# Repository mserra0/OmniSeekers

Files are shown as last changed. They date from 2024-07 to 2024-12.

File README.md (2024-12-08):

<div align="center">
 <a href="https://github.com/mserra0/OmniSeekers">
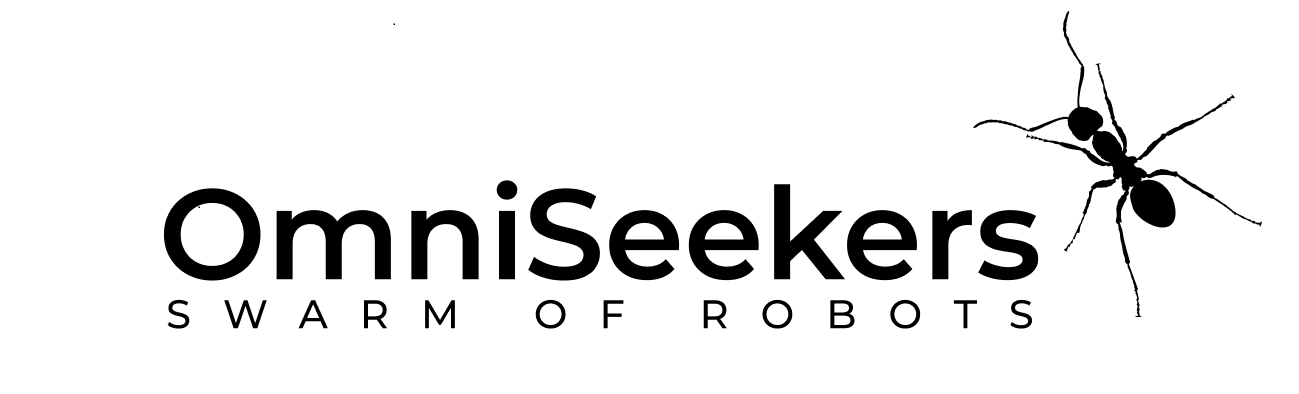
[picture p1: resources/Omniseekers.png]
    
 </a>
 <br/>
 <p align="center">
    Robotic project aimed at revolutionizing tasks such as Search and Rescue, with complete control of all robots in the swarm, also providing a promising development platform.
    <br />
 </p>
  <p align="center">
    <a href="https://www.youtube.com/watch?v=t2NAsWQEcVY&pp=ygULb21uaXNlZWtlcnM%3D">OmniSeekers Video Demo</a>
    <br />
 </p>
</div>

## Table of Contents
- [Description](#description)
  - [Structure](#structure)
  - [Dependencies](#dependencies)
- [Setup & Install](#setup--install)
- [Components](#components)
- [Details](#details)
  - [Software](#software)
  - [Hardware](#hardware)
- [Tools & Libraries](#tools--libraries)
  - [Tools](#software)
  - [Libraries](#hardware)
- [Technical Concepts](#technical-concepts)
  - [Bug Algorithm](#software)
  - [Odometry and Movement for 3-Wheeled Robots](#odometry-and-movement-for-3-wheeled-robots)
  - [Intra Robots Connection](#intra-robots-connection)
- [Demonstration](#demonstration)
- [To Do](#to-do)
- [References](#references)
- [Contributors](#contributors)
- [License](#license)

## Description
This project not only implements a swarm of omnidirectional robots but also serves as a multipurpose development platform. Designed to allow users to develop their own ideas affordably, this platform fosters innovation beyond its initial scope.

Our project focuses on creating a swarm of omnidirectional robots for Search-and-Rescue tasks without relying on GPS or SLAM mapping. We use exploration techniques based on Bug Algorithms, specifically the Swarm Gradient Bug Algorithm (SGBA) presented in the article "Minimal navigation solution for a swarm of tiny flying robots to explore an unknown environment". The aim is to provide an efficient solution for locating victims and targets in indoor environments where human access can be risky. Utilizing techniques from Swarm Robotics, we distribute the exploration tasks among multiple entities with simple objectives, enabling the use of affordable controllers instead of more costly computational solutions. A central server, employing computer vision and movement control techniques, coordinates the robots and recognizes victims when necessary.

We designed a 3-wheel omnidirectional robot base for our swarm, which uses fewer components, is lightweight, and offers full mobility. The ESP32 chipset serves as the robots' controller for video transmission and control, ensuring efficient communication with each other and the server. This design provides a fast and cost-effective implementation, making it an ideal foundation for further development and innovation.

<p align="center">
 
 
### Structure
* **resources**: This folder contains all the images and assets used in the README documentation to enhance visual understanding and presentation.
* **3d design**: This folder holds all the 3D models and parts designed for the project, facilitating the creation and assembly of the robot’s physical components.
* **circuits**: This directory includes circuit diagrams created with Fritzint and KiCad. It contains separate designs for the standard circuit and the PCB layout, ensuring comprehensive documentation of the electronic components.
* **server**: This section is a forked repository of the Cloud server, enabling remote control and data management for the robot via Google Cloud services.
* **coppelia**: This folder stores all the simulation files used in CoppeliaSim, where various algorithms like the Bug Algorithm and Wall Following are tested and validated.
* **src**: This folder stores all the functional code used to connect and move the robot with our server.

### Dependencies
- 
- 
- 
- 
- 
- 
- 
- 
- 

## Setup & Install
To start this project, several important aspects need to be considered. The primary factor enabling the functionality of this swarm of robots is server control. Therefore, installing and initializing the server is necessary for the complete functionality of the project.

The server configuration is specified in the server folder repository. You can clone the GitHub repository and follow the steps provided for correct installation. Note that the server is designed to be remote and runs on Google Cloud services. However, it can also be executed locally.

```
git clone https://github.com/Alvaritox11/ServerBidireccional.git
```

After this, you need to continue with the configuration of each robot.

Development was done using Visual Studio. Our robot operates with MicroPython. To work with MicroPython, follow these steps:

1. Install the following tool:
```sh
pip install esptool --user
```

2. Find the corresponding firmware for your controller on this page: `https://micropython.org/download/`. We recommend saving the downloaded `.bin` file in the user directory where you will execute the project.

3. Next, execute the following command, specifying the controller you are using and the port where it is connected. Ensure the controller is connected and hold down the Boot button while executing the command.

```sh
esptool --chip esp32 --port COM10 erase_flash
```

4. Once done, the next command deploys the downloaded firmware to the connected controller. Change the `ESP32_GENERIC-20240602-v1.23.0.bin` file to the one you downloaded. Again, hold down the Boot button while executing the command.

```sh
esptool --chip esp32 --port COM10 --baud 460800 write_flash -z 0x1000 ESP32_GENERIC-20240602-v1.23.0.bin
```

5. Now, install the PyMakr extension in Visual Studio Code. This extension offers functionalities similar to ArduinoIDE, such as connecting devices, disconnecting, uploading files, and viewing the Serial Monitor. Installing additional libraries in the program is unnecessary, as MicroPython already includes many commonly used libraries.

6. Finally, download the various files from the src folder corresponding to the MicroPython code and upload them to the controller.

All the specified steps for configuring the robot are detailed in the page:
`https://docs.micropython.org/en/latest/esp32/tutorial/intro.html`

## Components
In this section, we provide an overview of the key components that make up the OmniSeekers project. Each component has been carefully selected to ensure optimal performance, reliability, and integration within the system.
| Name | Units | Price |
|---|---|---|
| ESP-WROOM-32 38 PINOUT | 1 | 11.99 € |
| ESP32-CAM | 1 | 13.99 € |
| Motor Driver TD6612FNG | 2 | 4.95 €  |
| Motor N20 - 6V | 3 | 4.50 €  |
| Omnidirectional Wheel 58mm | 3 | 10.76 € |
| Hub 4mm | 3 | 0.99 €  |
| Micrometal Encoders x2 | 2 | 8.50 €  |
| UltraSound HC-SR04 | 3 | 1.80 €  |
| PowerBank 5000mAh | 1 | 11.99 € |
| Battery Holder 4xAA | 1 | 2.00 €  |
| PCB without shipping x5 pack (optional) | 1 | 17.99€  |
| **Total Price:** | | 139.01 € | 

The Total Price especified is only for a single robot.

## Details
In this section we will describe software and hardware details of our project. 

### Software
This section details the software architecture of the various interconnected modules of the robot, explaining how each component communicates and collaborates to ensure seamless operation.

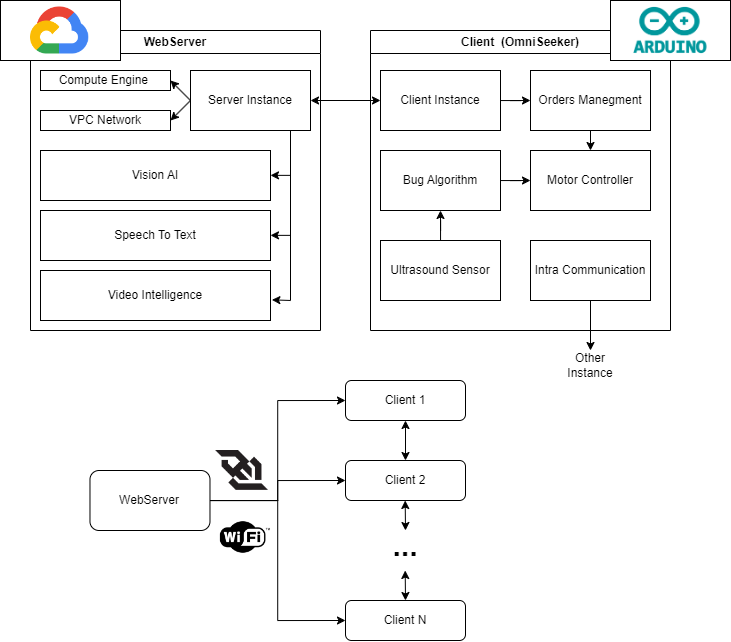
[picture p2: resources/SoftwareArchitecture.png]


### Hardware
#### Fritzint
Fritzint is used for connecting the robot's components to ensure proper functionality. This simple version provides a straightforward and efficient setup for integrating various hardware elements seamlessly.

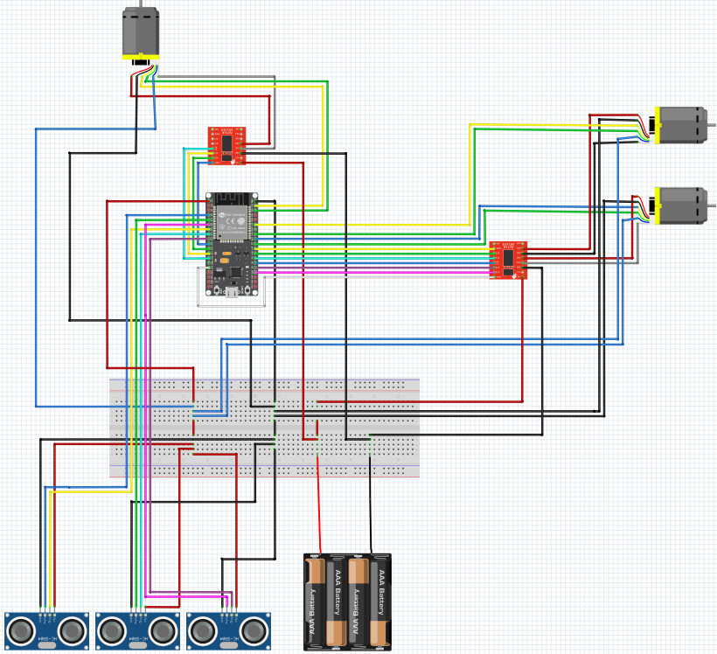
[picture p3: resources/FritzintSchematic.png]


#### KiCad
KiCad is utilized for creating a detailed schematic of the compact circuit to incorporate the PCB. This complex version ensures precise design and integration, enabling the development of high-quality printed circuit boards.

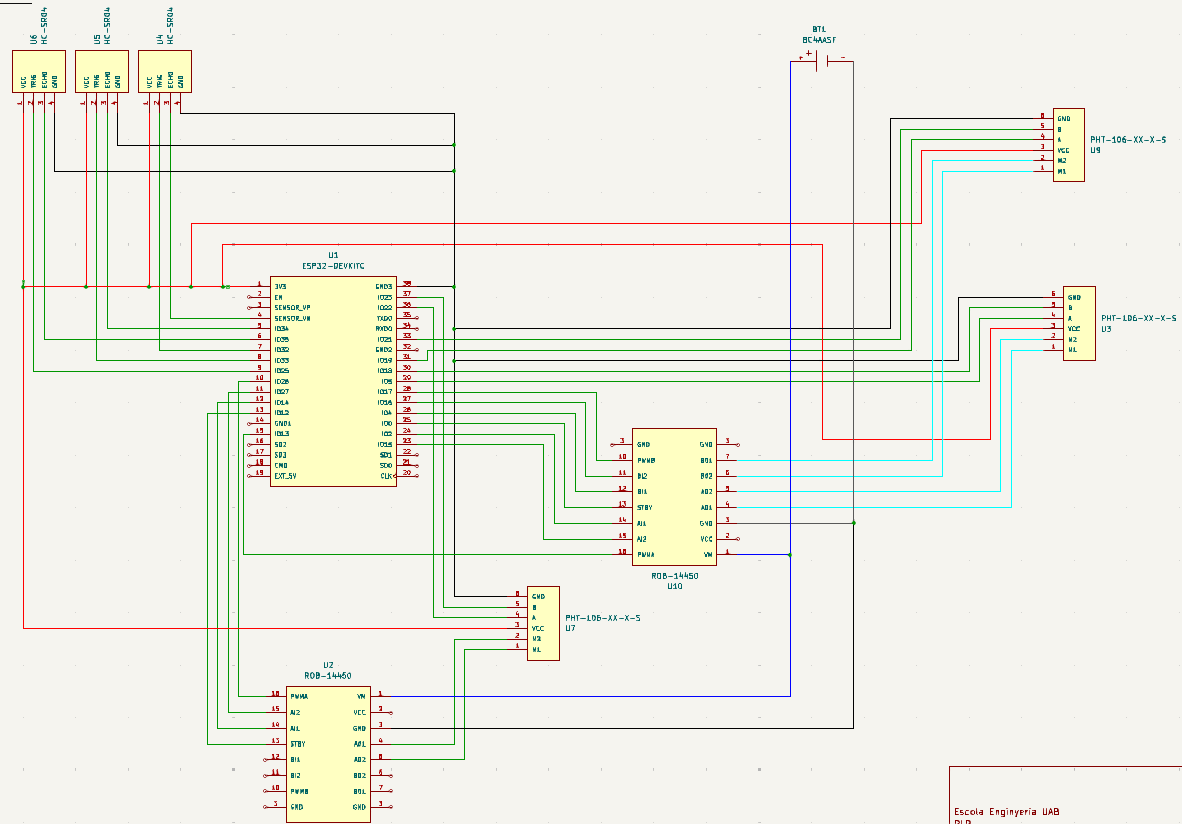
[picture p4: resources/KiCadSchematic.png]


#### Blender
Blender is used to design our custom 3D components, allowing us to make the robot as compact as possible. Each piece is meticulously crafted to fit our specific requirements, ensuring optimal use of space and functionality. All parts are then 3D printed using a compatible program tailored to the specific printer being used. You can find the pieces in the `3Ddesign` folder.



## Tools & Libraries
To fully develop the project we need a series of specific tools and libraries to obtain the result we expected.

### Tools
* **[CoppeliaSim](https://www.coppeliarobotics.com/):** For robot simulation.
* **[JupyterNotebook](https://jupyter.org/):** For programming the simulation of robots connecting with CoppeliaSim.
* **[VisualStudioCode](https://code.visualstudio.com/):** For robot development with MicroPython.
* **[Fritzint](https://fritzing.org/):** For first concept of hardware connection.
* **[KiCad](https://www.kicad.org/):** For final circuit design and production of PCB.

### Libraries
The libraries used are mainly to accurately simulate with the help of Jupyter Notebook in Coppelia. As previously mentioned, MicroPython already contains many of the necessary libraries to run the program, so installing these libraries is not required for real tests. However, to run simulation tests, the following libraries need to be installed with the following command:

```sh
pip install -r requirements.txt
```

## Technical Concepts
In this section, we delve into the key technical concepts that underpin the functionality and performance of the OmniSeekers project. Understanding these concepts is essential for appreciating the intricacies of the robot's design and operation. We cover algorithms for navigation, methods for precise movement, and communication protocols that enable seamless integration with cloud services.

### Bug Algorithm
The Bug algorithm is a family of simple yet effective pathfinding algorithms used in robotics for navigation and obstacle avoidance. These algorithms are particularly useful in environments where the robot has no prior knowledge of obstacles and must navigate in real-time. We have chosen this method because we do not use GPS or other mapping techniques such as SLAM.

#### Wall Following
A key aspect of the Bug algorithm is the Wall Following technique. When the robot encounters an obstacle, it switches to a wall-following behavior, moving along the boundary of the obstacle until it can resume its path towards the target. This method ensures that the robot can navigate around obstacles and continue towards its goal efficiently.

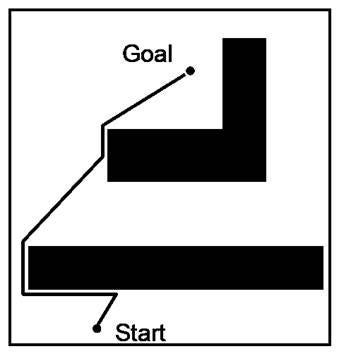
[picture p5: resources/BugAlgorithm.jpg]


### Odometry and Movement for 3-Wheeled Robots
Odometry is the use of data from motion sensors to estimate the change in position of a robot over time. For omnidirectional robots with three wheels, precise odometry is crucial to maintain accurate positioning and movement.

#### Omnidirectional Movement
An omnidirectional robot can move in any direction without changing its orientation. This is achieved through a specific arrangement of wheels and motors, allowing for smooth and flexible navigation. 

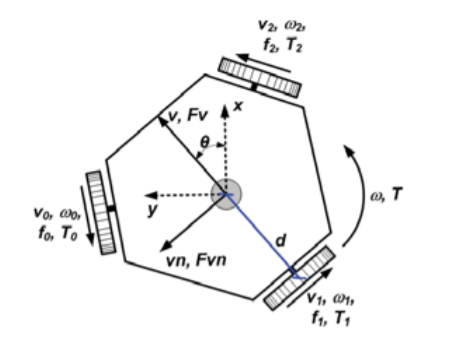
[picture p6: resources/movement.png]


### Intra Robots Connection

In our project, the intra-robot communication is achieved through Bluetooth Low Energy (BLE) technology. BLE is chosen for its low power consumption and sufficient range for indoor environments, making it ideal for the swarm of robots.

Each robot is equipped with an ESP32 chipset, which supports BLE. This allows the robots to send and receive messages from one another. The communication process involves broadcasting messages containing specific data packets. These packets include information such as the robot's unique identifier and other relevant status information.

One of the critical aspects of our BLE implementation is the use of Received Signal Strength Indicator (RSSI) values to estimate the proximity of the robots to one another. When a robot receives a message from another robot, it also records the RSSI value of the received message. The RSSI value indicates the power level of the received signal, which inversely correlates with the distance between the two robots.

To determine whether robots are near each other, the system uses a predefined RSSI threshold. If the RSSI value is above this threshold, the robots are considered to be close to one another. Conversely, if the RSSI value is below the threshold, the robots are deemed to be farther apart. This method allows the swarm to dynamically adjust its formation and coordination based on the proximity information.

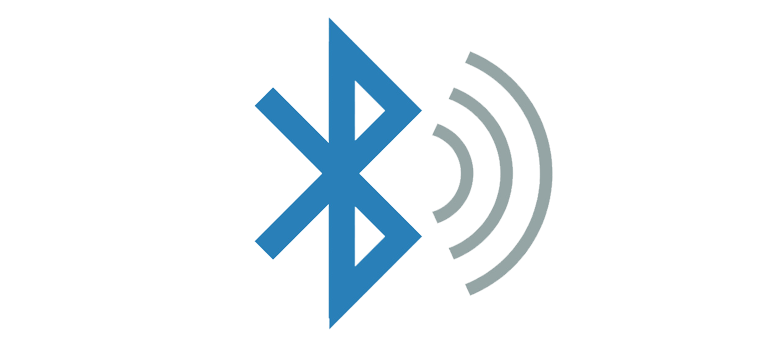
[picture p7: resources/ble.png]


## Demonstration
Here's an example of what our swarm of omnidirectional robots can achieve.

</p>
  <p align="center">
    <a href="https://www.youtube.com/watch?v=t2NAsWQEcVY&pp=ygULb21uaXNlZWtlcnM%3D">OmniSeekers Video Demo</a>
    <br />
</p>

## To Do
To advance this project, we have outlined several tasks that will significantly improve the robot's functionality and performance:

* **Connection Between Robots and Server:** Utilize an antenna to enhance the connection quality when using ESPNOW and WiFi. By improving the network infrastructure, we aim to expand the operational area, ensuring robust and reliable communication over a larger working field.

* **Robot Design:** Focus on miniaturizing both the robot's overall design and the PCB layout. This effort will make the robot more compact and agile, enhancing its operational efficiency and making it easier to navigate in confined spaces.

* **Bug Algorithm:** Upgrade the Bug Algorithm by integrating a gyroscope. This addition will provide more accurate directional changes and help maintain a consistent heading towards the target, improving the robot's navigation and obstacle avoidance capabilities.

## References

- 1. McGuire, K. N., De Wagter, C., Tuyls, K., Kappen, H. J., & de Croon, G. C. H. E. (2019). [Minimal navigation solution for a swarm of tiny flying robots to explore an unknown environment. Science Robotics](https://www.science.org/doi/10.1126/scirobotics.aaw9710)
- 2. maker.moekoe. (2023, 2 mayo). ESP32 based omnidirectional robots w/ camera | makermoekoe [Vídeo]. YouTube. https://www.youtube.com/watch?v=OIdMkZyhx7E
 
## Contributors

- **Marc Serra Ortega** - Universitat Autònoma de Barcelona (UAB)
- **Alvaro Javier Díaz Laureano** - Universitat Autònoma de Barcelona (UAB)
- **Jan Planas Batllori** - Universitat Autònoma de Barcelona (UAB)
- **Pol Pugibet Martinez** - Universitat Autònoma de Barcelona (UAB)

## License
This project is licensed under the [MIT License](LICENSE).

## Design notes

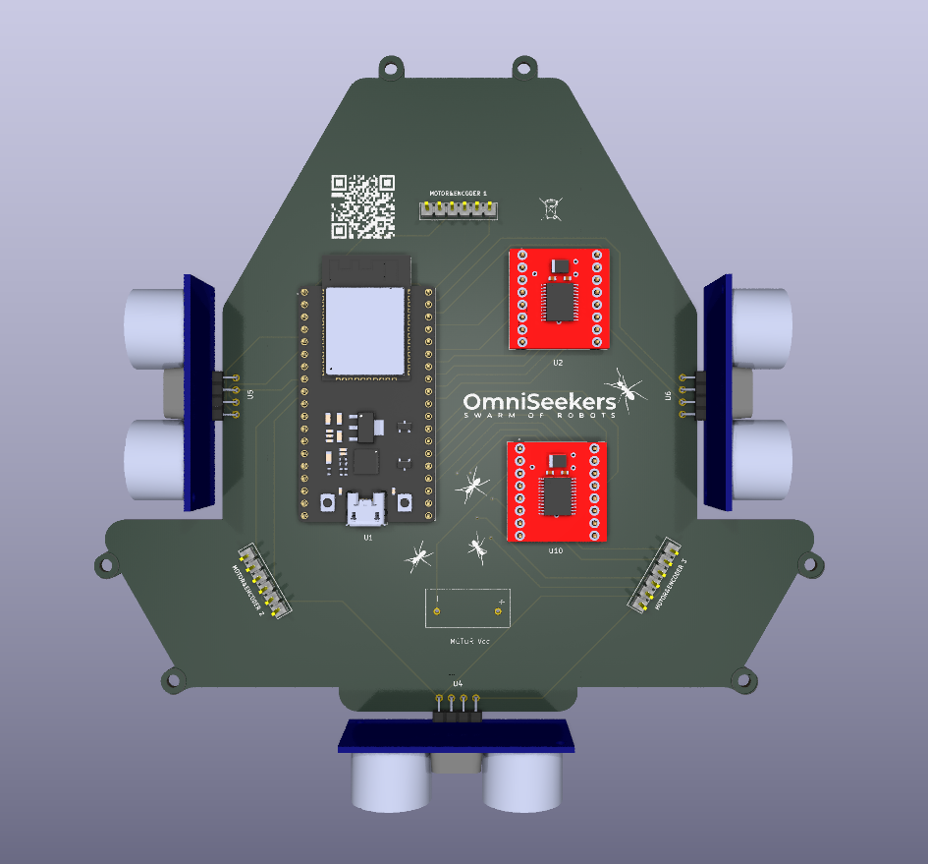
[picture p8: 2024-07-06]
resources/OmniSeekersPCB.png

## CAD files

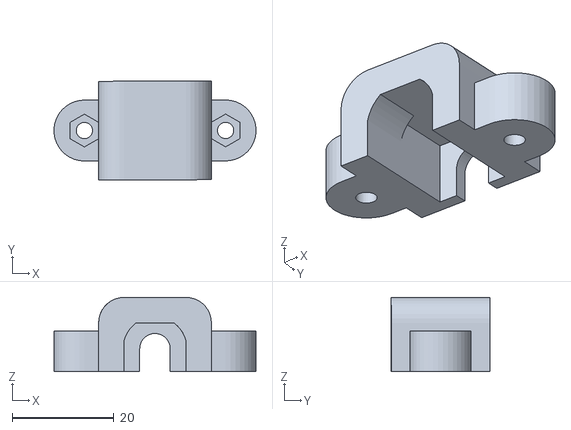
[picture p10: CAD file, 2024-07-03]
3d designs/motor_bracket.stl
39.8 x 19.4 x 14.6

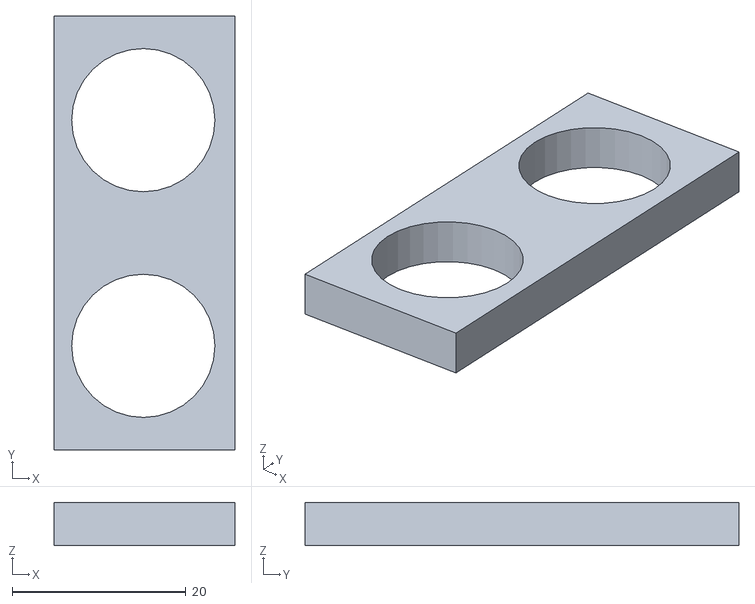
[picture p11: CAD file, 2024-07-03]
3d designs/ultrasonic_support.stl
20.8 x 50.0 x 5.00

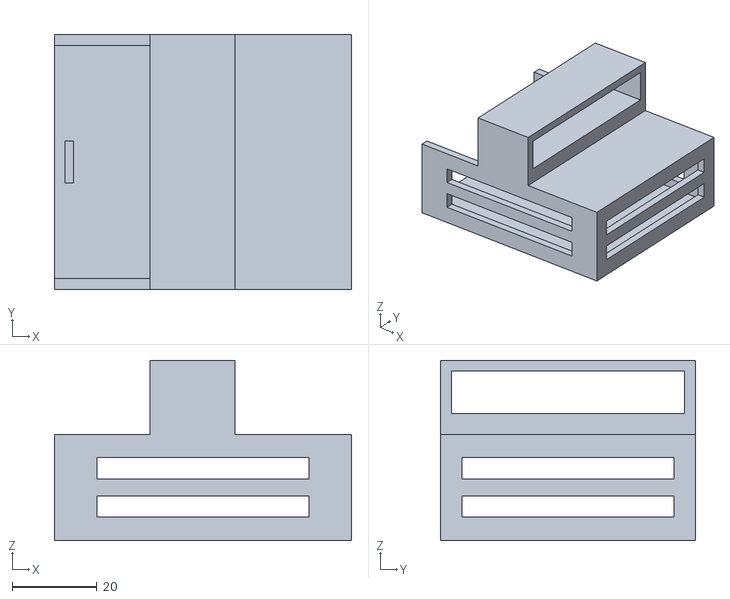
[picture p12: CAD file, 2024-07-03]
3d designs/battery_bracket.stl
70.0 x 60.0 x 42.5

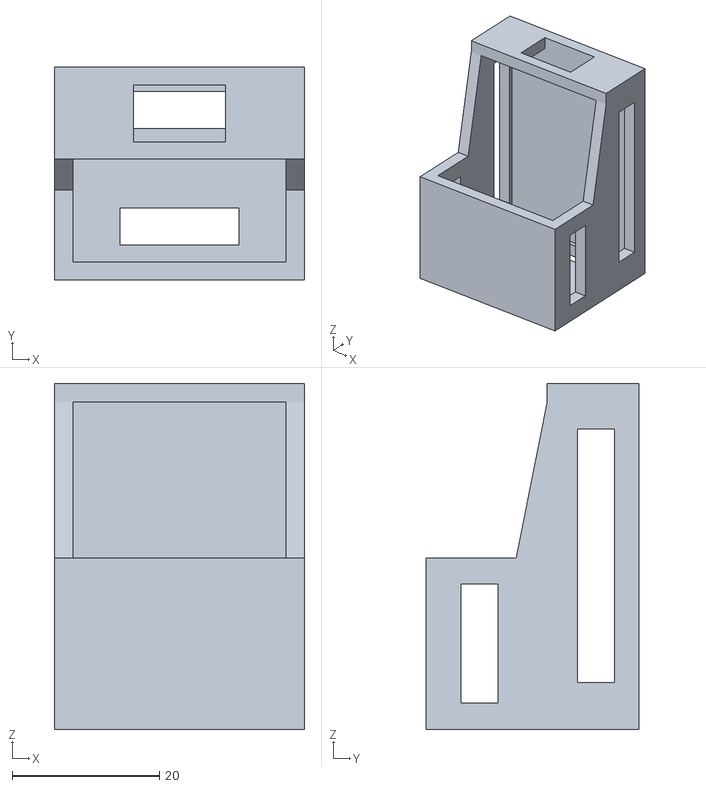
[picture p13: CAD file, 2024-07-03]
3d designs/esp32_cam_bracket.stl
34.0 x 29.0 x 47.0

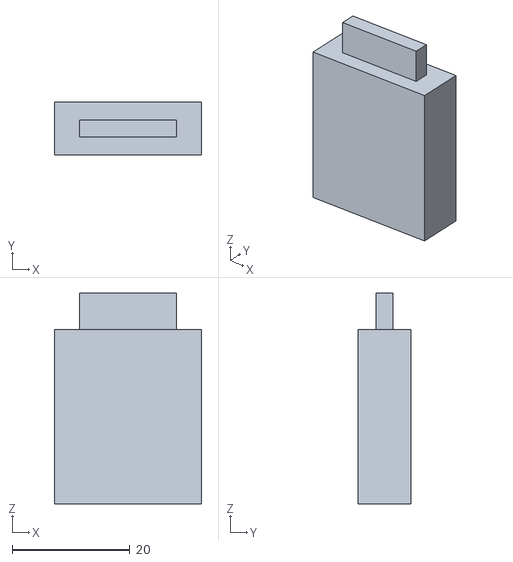
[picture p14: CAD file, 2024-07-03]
3d designs/column.stl
25.0 x 9.00 x 35.8

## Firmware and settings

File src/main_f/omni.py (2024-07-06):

from machine import Pin,PWM
from time import sleep
from .hcsr04 import HCSR04
from .TB6612FNG import Motor
import math
import time
from math import cos, sin, pi
import random

WheelRadius = 0.053
robot_radius = 0.12
dt = 0.1

def calculate_wheel_velocities(speed, rotation, orientation):
    alpha = [0, 2 * math.pi / 3, -2 * math.pi / 3]  
    Vx = speed * cos(orientation)
    Vy = speed * sin(orientation)
    omega = rotation / WheelRadius
    
    V_wheels = []
    for a in alpha:
        V_wheel = -Vx * cos(a) + Vy * sin(a) + omega * WheelRadius
        V_wheels.append(V_wheel)
    
    return V_wheels

def calc_h(distance_front, distance_back):
    c = math.sqrt(distance_front**2 + distance_back**2)
    h = distance_front * distance_back / c
    return h

class OmniSeeker():
    def __init__(self):
        # FLAGS ACTIVADOS SIEMPRE QUE HAYA DISTANCIA MINIMA DE 20 CM
        self.followingWall = False
        self.flagSideBack = False # Activar solo si esta a menos de 20 cm
        self.flagSideLeft = False # Activar solo si esta a menos de 20 cm
        self.flagSideRight = False
        self.movement = 0 #1:right, -1:left, 2:forward
        self.distance = float('inf')
        self.dist_diff = -1
        self.generated_movement = False
        self.vel1 = 0
        self.vel2 = 0
        self.vel3 = 0
        self.Ypos = 0
        self.Xpos = 0
        self.theta = pi/2
        
    def addMotors(self, STBY_1, AIN1_1, AIN2_1, PWMA_1, BIN1_1, BIN2_1, PWMB_1, STBY_2, AIN1_2, AIN2_2, PWMA_2, freq):
        self.motor1 = Motor(STBY_1, AIN1_1, AIN2_1, PWMA_1, freq)
        self.motor2 = Motor(STBY_1, BIN1_1, BIN2_1, PWMB_1, freq)
        self.motor3 = Motor(STBY_2, AIN1_2, AIN2_2, PWMA_2, freq)
        
    def addSensors(self, trigger_1, echo_1, trigger_2, echo_2, trigger_3, echo_3):
        self.sensorBack = HCSR04(trigger_1, echo_1)
        self.sensor2 = HCSR04(trigger_2, echo_2)
        self.sensor3 = HCSR04(trigger_3, echo_3)
    
    def moveRobot(self, speed, rotation, orientation): # MOVE FORMWARD, MOVE BACKWARD, ROTATE LEFT, ROTATE RIGHT, MOVE LEFT, MOVE RIGHT
        wheel_velocities = calculate_wheel_velocities(speed, rotation, orientation)
        
        self.vel1 = wheel_velocities[1]
        self.vel2 = wheel_velocities[2]
        self.vel3 = wheel_velocities[0]
        
        if self.vel1 < 0:
            dir1_0 = 1
            dir1_1 = 0
        else:
            dir1_0 = 0
            dir1_1 = 1
            
        if self.vel2 < 0:
            dir2_0 = 1
            dir2_1 = 0
        else:
            dir2_0 = 0
            dir2_1 = 1
            
        if self.vel3 < 0:
            dir3_0 = 0
            dir3_1 = 1
        else:
            dir3_0 = 1
            dir3_1 = 0
        
        self.motor1.move_motor(dir1_0, dir1_1, abs(self.vel1), 1)
        self.motor2.move_motor(dir2_0, dir2_1, abs(self.vel2), 1)
        self.motor3.move_motor(dir3_0, dir3_1, abs(self.vel3), 1)
        
    def correctTheta(self):
        if self.theta < 3*pi/4 and self.theta > pi/4:
            self.theta = pi/2
        elif self.theta > 3*pi/4 and self.theta < 5*pi/4:
            self.theta = pi
        elif self.theta > 5*pi/4 and self.theta < 7*pi/4:
            self.theta = 3*pi/2
        else:
            self.theta = 0
            
    def stop(self):
        self.moveRobot(0, 0, 0)

    def getDistance(self, sensor):
        distance = sensor.distance_cm()
        if distance is not None:
            return round(distance, 1)
        else:
            return 9999
        
    def sweeping(self):
        print('Sweeping')
        min_distance = float('inf')
        start_time = time.time()
        
        while time.time() - start_time < 1:
            distance = self.getDistance(self.sensorBack)
            if distance < 50:
                min_distance = min(min_distance, distance)
            self.moveRobot(0, -(12.5/distance) * self.movement, 0)
            
        start_time = time.time()
        while time.time() - start_time < 2:
            distance = self.getDistance(self.sensorBack)
            if distance < 50:
                min_distance = min(min_distance, distance)
            self.moveRobot(0, (12.5/distance) * self.movement, 0)
        
        if min_distance < 50:
            distance = self.getDistance(self.sensorBack)
            while abs(distance - min_distance) > 0.1:
                distance = self.getDistance(self.sensorBack)
                self.moveRobot(0, -(12.5/distance) * self.movement, 0)
            
            while int(distance) > 20:
                self.moveRobot(1, 0, math.pi / 2)
                distance = self.getDistance(self.sensorBack)
            self.followingWall = True
            print('FollowingWalls')
        else:
            self.moveRobot(0, -(12.5/distance) * self.movement, 0)
            time.sleep(1)
        self.stop()
        
    def get_dist_diff(self):
        distance = self.getDistance(self.sensorBack)
        diff_dist = self.distance - distance
        return distance, diff_dist
    
    def correct_position(self):
        distance = self.getDistance(self.sensorBack)
        diff_dist = self.distance - distance
        self.distance = distance
        dist_diff_th = self.dist_diff - 3 < diff_dist < self.dist_diff + 3

        if distance < 15 and dist_diff_th:
            print('Correcting position')
            while distance < 20:
                distance = self.getDistance(self.sensorBack)
                self.moveRobot(1, 0, 3 * math.pi / 2)
            self.stop()
            time.sleep(0.1)
            self.moveRobot(0, -0.1 * self.movement, 0)
            time.sleep(0.5)
        elif distance > 30 and dist_diff_th:
            time.sleep(1)
            print('Correcting position')
            distance = self.getDistance(self.sensorBack)
            if distance > 50:
                print('Not following wall')
                self.followingWall = False
                return
            while distance > 20:
                distance = self.getDistance(self.sensorBack)
                self.moveRobot(1, 0, math.pi / 2)
            self.stop()
            time.sleep(0.1)
            self.moveRobot(0, 0.1 * self.movement, 0)
            time.sleep(0.5)
        self.distance = distance
        self.dist_diff = diff_dist
        
    def setFlags(self):
        self.flagSideRight = self.getDistance(self.sensorRight) < 20
        self.flagSideLeft = self.getDistance(self.sensorLeft) < 20
        if self.movement != 2:
            self.flagSideBack = self.getDistance(self.sensorBack) < 50
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

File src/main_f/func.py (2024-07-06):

import network as net
import uasyncio as a
import json
from random import randint
from machine import Pin
import gc

from math import pi
from .omni import OmniSeeker

from async_websocket_client import AsyncWebsocketClient


# trying to read config --------------------------------------------------------
# if config file format is wrong, exception is raised and program will stop
print("Trying to load config...")

f = open("../config.json")
text = f.read()
f.close()
config = json.loads(text)
del text
# ------------------------------------------------------------------------------

print("Create WS instance...")
# create instance of websocket
ws = AsyncWebsocketClient(config['socket_delay_ms'])
print("Created ws.")

print("Create OmniSeeker instance...")
omni = OmniSeeker()
omni.addMotors(0, 2, 15, 13, 4, 16, 17, 26, 14, 27, 12, 5000)
print("Created omni.")


# this lock will be used for data interchange between loops --------------------
# better choice is to use uasynio.queue, but it is not documented yet
lock = a.Lock()
# this array stores messages from server
data_from_ws = []
# ------------------------------------------------------------------------------

# SSID - network name
# pwd - password
# attempts - how many time will we try to connect to WiFi in one cycle
# delay_in_msec - delay duration between attempts
async def wifi_connect(SSID: str, pwd: str, attempts: int = 3, delay_in_msec: int = 200) -> net.WLAN:
    wifi = net.WLAN(net.STA_IF)

    wifi.active(1)
    count = 1

    while not wifi.isconnected() and count <= attempts:
        print("WiFi connecting. Attempt {}.".format(count))
        if wifi.status() != net.STAT_CONNECTING:
            wifi.connect(SSID, pwd)
        await a.sleep_ms(delay_in_msec)
        count += 1

    if wifi.isconnected():
        print("ifconfig: {}".format(wifi.ifconfig()))
    else:
        print("Wifi not connected.")

    return wifi


# ------------------------------------------------------
# Main loop function: send data to server to keep connected.
# This code emulates main control cycle for controller.
async def blink_loop():
    global lock
    global data_from_ws
    global ws

    # Main "work" cycle. It should be awaitable as possible.
    while True:
        if ws is not None:
            if await ws.open():
                await ws.send('SOS!')

            # lock data archive
            await lock.acquire()
            if data_from_ws:
                data_from_ws = []
            lock.release()
            gc.collect()

        await a.sleep_ms(400)
# ------------------------------------------------------

# ------------------------------------------------------
# Task for read loop
async def read_loop():
    global config
    global lock
    global data_from_ws

    # may be, it
    wifi = await wifi_connect(config["wifi"]["SSID"], config["wifi"]["password"])
    while True:
        gc.collect()
        if not wifi.isconnected():
            wifi = await wifi_connect(config["wifi"]["SSID"], config["wifi"]["password"])
            if not wifi.isconnected():
                await a.sleep_ms(config["wifi"]["delay_in_msec"])
                continue
        try:
            print("Handshaking...")
            # connect to test socket server with random client number
            if not await ws.handshake("{}{}".format(config["server"], randint(1, 100))):
                raise Exception('Handshake error.')
            print("...handshaked.")

            mes_count = 0
            while await ws.open():
                data = await ws.recv()
                print("Data: " + str(data) + "; " + str(mes_count))
                data = data.split("=")
                if len(data) == 2 and data[0] == 'move':
                    move = int(data[1])
                    if move == 0:
                        omni.stop()
                    elif move == 3:
                        omni.moveRobot(0.75, 0, pi/2)
                    elif move == 4:
                        omni.moveRobot(-0.75, 0, pi/2)
                    elif move == 1:
                        omni.moveRobot(0.75, 0, pi)
                    elif move == 2:
                        omni.moveRobot(-0.75, 0, pi)
                    elif move == 5:
                        omni.moveRobot(0, pi/8, 0)
                    elif move == 6:
                        omni.moveRobot(0, -pi/8, 0)

                    print(f"Move command received: {move}")
                else:
                    print("Invalid message format")
                # close socket for every 10 messages (even ping/pong)
                if mes_count == 10:
                    await ws.close()
                    print("ws is open: " + str(await ws.open()))
                mes_count += 1

                if data is not None:
                    await lock.acquire()
                    data_from_ws.append(data)
                    lock.release()

                await a.sleep_ms(50)
        except Exception as ex:
            print("Exception: {}".format(ex))
            await a.sleep(1)
# ------------------------------------------------------

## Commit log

2024-07-03 3d designs uploaded
    [battery_bracket.stl, column.stl, esp32_cam_bracket.stl]
2024-07-03 rest of 3d designs
    [motor_bracket.stl, ultrasonic_support.stl]
2024-07-09 Insercion fritz y cambios readme
    [circuit_omniseek.fzz]
2024-07-09 Cmabio de carpeta
